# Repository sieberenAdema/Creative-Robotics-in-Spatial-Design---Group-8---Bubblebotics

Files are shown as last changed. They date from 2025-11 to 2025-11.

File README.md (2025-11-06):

### Creative Robotics in Spatial Design   Group 8 - Bubblebotics ###
ARIT1507 Creative Robotics in Spatial Design (2025/26 Q1) - Group 8 “Bubblebotics”
Soft pneumatic installation controlled by an ESP32 and a local voice interface.

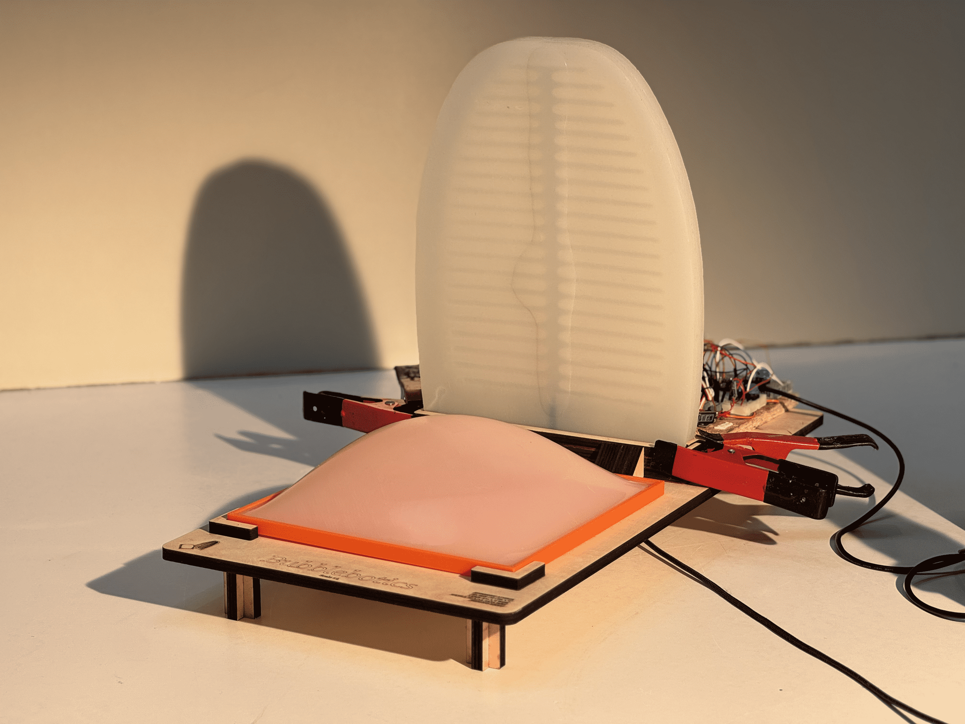
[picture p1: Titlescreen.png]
Bubblebotics


**TL;DR**: Speak a mood (Sleep / Play / Focus) → PC classifies the phrase → sends `MODE:*` over serial → ESP32 drives pump + valves to inflate/deflate a silicone petal and bubble → a synchronized video plays on a screen.

## 1) Project overview
This project explores ambient, soft robotic behaviors for spatial design.
Two soft pneumatic actuators (referred to as 'petal' and 'bubble') are controlled using an ESP32 microcontroller and a trained sentence classifier (all-MiniLM-L6-v2) running on a PC to parse voice inputs.

The three modes are:
- **Sleep** — calm, slow inflation (petal only)
- **Play** — lively, bigger motion (petal 2 + bubble)
- **Focus** — poised, attentive motion (petal 1 + bubble)

The actuators are made of flexible silicone that allow it to bend when air is pumped into it via a small tube.

Microphone → SpeechToText → Text Classifier → Serial Communication → ESP32 → Pump/Valves → Actuators
(from Text Classifier) → VLC → Screen Animation

---
## 2) Hardware
**Core components**
- An **ESP32 board (MicroPython)** to control the pump and solenoid valves.
- A **Grove 1.1 MOSFET driver board** to switch the pump on/off.
- Two silicone components, a **silicone pneumatic petal** and a **bubble actuator**, which inflates and bends when air is pumped in.
- A **12v Pump** to inflate the actuators
- A set of **4 12v solenoid valves** to control airflow to and from the actuators
- 3 **Buttons** to mannually actuate the different modes (The buttons are wired to ground. They use the internal Pull-ups on the ESP32)
- A **Breadboard** to connect all components, **tubing**, **printed manifolds**, **wireing** 

### ESP32 pinout
Refer to **wireing.svg** for exact wireing of all components

Making process video:
https://www.youtube.com/embed/A4v-PSnlZ5w?si=yJa3w9C8E-f-ZMew

## 3) Software
- **ESP32 (MicroPython v1.26.1)** runs valve/pump control and button handling.
- **Windows PC (Python)** runs voice → text, classifies to a mode, sends serial command, and drives VLC for videos.  

### Libraries used:
- **speechrecognition** — captures microphone audio and uses Google Web Speech API to transcribe short phrases.
- **sentence-transformers** — embeds text into vectors for semantic classification.
- **scikit-learn** — provides the probabilistic classifier used to map phrases → modes.
- **joblib** — loads the pre‑trained classifier from `model_classifier_augmented.pkl`.
- **numpy** — vector math for embeddings and probabilities.
- **pyserial** — lists serial ports and sends ASCII `MODE:*` lines to the ESP32 at 115200 baud.
- **python-vlc** — plays the inflate/deflate videos and loops the active mode video.
- **tkinter** — simple window to host the embedded VLC player.
- **collections.deque** — lightweight rolling log of recent phrases/modes.
- **MicroPython `machine`, `Pin`, `UART`** — access GPIO and optional UART on the ESP32.
- **MicroPython `select`** — non‑blocking read of USB CDC for serial commands.

## 4) Modes & behaviors
Timing constants (These are still being tuned and depend highly on the strength of pump used and the geometry of the silicone to be inflated):  
`INFLATE_TIME = 12 s` 
`DEFLATE_TIME = 6 s`

**Valve mapping per mode**
- **Sleep** : `Petal 1 = ON`, `Petal 2 = OFF`, `Bubble = OFF`, `Exhaust = OFF`
- **Play** : `Petal 1 = OFF`, `Petal 2 = ON`, `Bubble = ON`,  `Exhaust = OFF`
- **Focus** : `Petal 1 = ON`, `Petal 2 = OFF`, `Bubble = ON`,  `Exhaust = OFF`

**Cycle logic**
1) On mode change: **deflate** (open *all* valves + exhaust for 6 s)  
2) Then **inflate** the new mode: open that modes valves, run pump for 12 s, stop pump.

## 5) Steps required to get up and running
### A) Flash ESP32 with MicroPython (once)

- Use Windows Device Manager to detect which port the ESP32 is connected to
- Get the latest driver for ESP32 from https://micropython.org/download/ESP32_GENERIC/

```CMD
# Install tooling
python -m pip install --upgrade esptool mpremote setuptools
# Erase and flash (adjust COM port and .bin path)
esptool --port COM5 erase_flash
esptool --chip esp32 --port COM5 --baud 460800 \
  write_flash -z 0x1000 "C:\\Users\\flori\\Desktop\\indiv\\ESP32_GENERIC-20250911-v1.26.1.bin"
```
### B) Upload firmware to the board
```CMD
# List files on the board
mpremote connect COM5 fs ls

# Replace existing main.py
mpremote connect COM5 fs rm "main.py"   
mpremote connect COM5 fs cp "C:\\Users\\flori\\Desktop\\indiv\\main.py" :

# Run & view REPL output
mpremote connect COM5 run "C:\\Users\\flori\\Desktop\\indiv\\main.py"
mpremote connect COM5 repl
```
### C) Set up the PC app
```CMD
pip install speechrecognition sentence-transformers scikit-learn joblib pyserial python-vlc tkinter numpy
```
Place the files next to `main_with_video.py`:
```
model_classifier_augmented.pkl
embedder_augmented/            # SentenceTransformer folder or model reference
videos/
  sleep_inflation.mp4
  sleep_deflation.mp4
  play_inflation.mp4
  play_deflation.mp4
  focus_inflation.mp4
  focus_deflation.mp4
```
Ensure **VLC** is installed at `C:\Program Files\VideoLAN\VLC` (or x86). The script auto-adds that path.

### D) Run
```CMD
python path\to\main_with_video.py
```
- The script will auto‑detect the serial port (or set `SERIAL_PORT = "COM3"`).
- Speak phrases like “**I’m tired**” (Sleep), “**let’s play music**” (Play), “**I need to focus**” (Focus).
- The window should loop the current mode’s *inflate* video, and transition with *deflate* → *inflate* on changes.

## 6) Troubleshooting
- **No serial ports found** — Unplug the board. Check Device Manager. Try a different cable (make sure that the micro-USB is actually a data cable); set `SERIAL_PORT` explicitly in the code.
- **`libvlc.dll` not found** — Install VLC (desktop), then re‑run. Paths are auto‑added from `Program Files`.
- **Videos don’t play** — Verify file names and paths in `VIDEO_PATHS`.
- **Classifier always “low confidence”** — Lower `CONF_THRESHOLD` (e.g., 0.3) or add more training data. Speak closer to mic. Reduce background noise.
- **Pump acts weird / Valves act weird** — Check that wiring is correct, check that all wires are still in the right position.

## 7) Tips
- Make sure that the tubing is tight at valves, pump, manifold and silicone.
- Be carefull with the amount of pressure you add into the silicone actuators. In the current set-up the pump is strong enough rip the silicone should it run for too long.

## 8) References & handy commands

* MicroPython for ESP32: [https://micropython.org/download/ESP32_GENERIC/](https://micropython.org/download/ESP32_GENERIC/)
* `machine` module docs: [https://docs.micropython.org/en/latest/library/machine.html](https://docs.micropython.org/en/latest/library/machine.html)
* Getting started (ESP32/ESP8266): [https://randomnerdtutorials.com/getting-started-micropython-esp32-esp8266/](https://randomnerdtutorials.com/getting-started-micropython-esp32-esp8266/)
* ESP32 MicroPython tutorials: [https://newbiely.com/tutorials/esp32-micropython/esp32-micropython-ultrasonic-sensor](https://newbiely.com/tutorials/esp32-micropython/esp32-micropython-ultrasonic-sensor)
* Sentence transformer model: [https://huggingface.co/sentence-transformers/all-MiniLM-L6-v2](https://huggingface.co/sentence-transformers/all-MiniLM-L6-v2)

**Usefull CMD snippets**

```CMD
# File operations
mpremote connect COM5 fs ls
mpremote connect COM5 fs rm "main.py"
mpremote connect COM5 fs cp "C:\\Users\\flori\\Desktop\\indiv\\main.py" :
mpremote connect COM5 run "C:\\Users\\flori\\Desktop\\indiv\\main.py"
mpremote connect COM5 repl

# Run PC app
python "C:\\Users\\flori\\Desktop\\bubble\\brain_serial_llm.py"
python "C:\\Users\\flori\\Desktop\\bubble\\tinyllama_brain_serial_llm.py"
```

---

## 9) Cite

> Bubblebotics (2025). Creative Robotics in Spatial Design, TU Delft. https://github.com/sieberenAdema/Creative-Robotics-in-Spatial-Design---Group-8---Bubblebotics

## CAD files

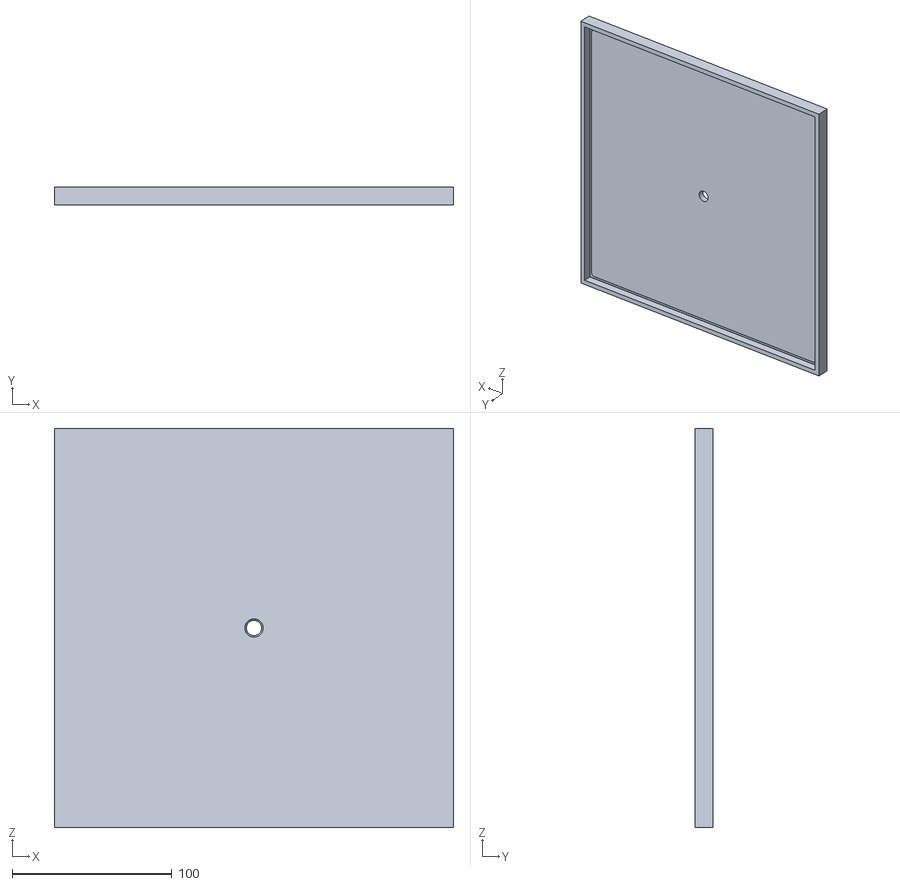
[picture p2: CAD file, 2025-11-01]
Geometry/250 bubble simple square.STL
250.0 x 11.0 x 250.0

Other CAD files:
Geometry/robot.dxf

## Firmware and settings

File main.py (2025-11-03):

# esp32_mode_control_serial.py
# Your valve/pump control + buttons + non-blocking serial listener for MODE:SLEEP/PLAY/FOCUS

from machine import Pin, UART
import sys, time

# CONFIGURE PINS (adjust as needed)
# Outputs
PUMP_PIN = 23          # MOSFET SIG (pump)
EXHAUST_VALVE_PIN = 18 # ULN input for exhaust valve (deflate)
PETAL_1_VALVE = 19     # ULN input for Sleep valve
PETAL_2_VALVE = 17     # ULN input for Play valve
BUBBLE_VALVE = 16      # ULN input for Bubble valve

# Inputs (buttons, active LOW)
BTN_SLEEP_PIN = 12
BTN_PLAY_PIN  = 13
BTN_FOCUS_PIN = 14

# Timing (seconds)
INFLATE_TIME = 10
DEFLATE_TIME = 7
DEBOUNCE_MS = 200

# SERIAL MODE
USE_USB_SERIAL = True  # True = read commands from USB CDC (no extra wires)
# If you want UART pins instead, set to False and configure below:
UART_PORT = 2           # UART(2) is usually free
UART_BAUD = 115200
UART_TX = 4             # pick free pins that don't clash!
UART_RX = 2

# SETUP HARDWARE
pump = Pin(PUMP_PIN, Pin.OUT)
exhaust_valve = Pin(EXHAUST_VALVE_PIN, Pin.OUT)
P_1_valve = Pin(PETAL_1_VALVE, Pin.OUT)
P_2_valve = Pin(PETAL_2_VALVE, Pin.OUT)
bubble_valve = Pin(BUBBLE_VALVE, Pin.OUT)

btn_sleep = Pin(BTN_SLEEP_PIN, Pin.IN, Pin.PULL_UP)
btn_play  = Pin(BTN_PLAY_PIN, Pin.IN, Pin.PULL_UP)
btn_focus = Pin(BTN_FOCUS_PIN, Pin.IN, Pin.PULL_UP)

if not USE_USB_SERIAL:
    uart = UART(UART_PORT, baudrate=UART_BAUD, tx=UART_TX, rx=UART_RX)

# Ensure everything off initially
def all_off():
    pump.value(0)
    exhaust_valve.value(0)
    P_1_valve.value(0)
    P_2_valve.value(0)
    bubble_valve.value(0)

all_off()

# Mode name constants
MODE_SLEEP = "Sleep"
MODE_PLAY  = "Play"
MODE_FOCUS = "Focus"
current_mode = MODE_PLAY

# HELPER FUNCTIONS
def set_mode_valves(mode):
    if mode == MODE_SLEEP:
        P_1_valve.value(1); P_2_valve.value(0); bubble_valve.value(0); exhaust_valve.value(0)
    elif mode == MODE_PLAY:
        P_1_valve.value(0); P_2_valve.value(0); bubble_valve.value(1); exhaust_valve.value(0)
    elif mode == MODE_FOCUS:
        P_1_valve.value(1); P_2_valve.value(0); bubble_valve.value(1); exhaust_valve.value(0)
    else:
        P_1_valve.value(0); P_2_valve.value(0); bubble_valve.value(0); exhaust_valve.value(0)

def deflate_cycle():
    print("Deflate: opening exhaust")
    pump.value(0)
    # open all valves so everything can dump
    exhaust_valve.value(1)
    P_1_valve.value(1)
    P_2_valve.value(1)
    bubble_valve.value(1)
    time.sleep(DEFLATE_TIME)
    # close exhaust
    exhaust_valve.value(0)
    P_1_valve.value(0)
    P_2_valve.value(0)
    bubble_valve.value(0)
    print("Deflate complete")

def inflate_for_mode(mode):
    print("Inflating for mode:", mode)
    set_mode_valves(mode)
    time.sleep(0.2)  # let valves open
    pump.value(1)
    time.sleep(INFLATE_TIME)
    pump.value(0)
    exhaust_valve.value(0)  # keep mode valves open
    print("Inflation done (pump stopped)")

def change_mode(new_mode):
    global current_mode
    if new_mode == current_mode:
        print("Already in", new_mode, "- no change")
        return
    print("Switching from", current_mode, "to", new_mode)
    deflate_cycle()
    inflate_for_mode(new_mode)
    current_mode = new_mode
    print("Mode is now", current_mode)

print("Starting - inflating initial mode:", current_mode)
inflate_for_mode(current_mode)

# BUTTONS (debounced)
last_btn_times = {"sleep": 0, "play": 0, "focus": 0}
def button_pressed(key):
    now = time.ticks_ms()
    last = last_btn_times[key]
    if time.ticks_diff(now, last) < DEBOUNCE_MS:
        return False
    last_btn_times[key] = now
    return True

# SERIAL PARSER (non-blocking)
# Accepts lines like: MODE:SLEEP / MODE:PLAY / MODE:FOCUS
buf = ""

def poll_serial_line():
    global buf
    try:
        if USE_USB_SERIAL:
            # read one char if available from USB CDC without blocking
            import select
            r, _, _ = select.select([sys.stdin], [], [], 0)
            if r:
                ch = sys.stdin.read(1)
            else:
                ch = None
        else:
            if not hasattr(uart, "any") or not uart.any():
                ch = None
            else:
                ch = uart.read(1)
                if ch is not None:
                    ch = ch.decode("utf-8", "ignore")
        if ch:
            buf += ch
            if ch == "\n":
                line = buf.strip()
                buf = ""
                return line
    except Exception as e:
        # swallow transient decode/IO issues
        buf = ""
    return None

def handle_command(line: str):
    up = line.strip().upper()
    if up == "MODE:SLEEP":
        change_mode(MODE_SLEEP)
    elif up == "MODE:PLAY":
        change_mode(MODE_PLAY)
    elif up == "MODE:FOCUS":
        change_mode(MODE_FOCUS)
    else:
        print("Unknown command:", line)

# MAIN LOOP

try:
    while True:
        # 1) Serial
        line = poll_serial_line()
        if line:
            print("Received:", line)
            handle_command(line)

        # 2) Buttons (active LOW)
        if btn_sleep.value() == 0 and button_pressed("sleep"):
            change_mode(MODE_SLEEP)
        elif btn_play.value() == 0 and button_pressed("play"):
            change_mode(MODE_PLAY)
        elif btn_focus.value() == 0 and button_pressed("focus"):
            change_mode(MODE_FOCUS)

        time.sleep_ms(30)

except KeyboardInterrupt:
    print("Interrupted, turning everything off")
    all_off()

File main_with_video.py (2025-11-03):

# voice_to_mode_videos_fixed.py
# Mic → Google STT → Local Classifier → MODE:SLEEP/PLAY/FOCUS over serial
# + VLC video transitions (deflate old mode → inflate new mode)
#
# Requires:
# pip install speechrecognition sentence-transformers scikit-learn joblib pyserial python-vlc tkinter

import os
import time
import threading
import serial, serial.tools.list_ports
import speech_recognition as sr
from sentence_transformers import SentenceTransformer
import joblib
import numpy as np
from collections import deque
import tkinter as tk
import vlc

# ========== VLC SETUP ==========
VLC_PATHS = [
    r"C:\Program Files\VideoLAN\VLC",
    r"C:\Program Files (x86)\VideoLAN\VLC",
]
for p in VLC_PATHS:
    if os.path.exists(os.path.join(p, "libvlc.dll")):
        os.add_dll_directory(p)
        print(f"[VLC] Using VLC from: {p}")
        break

# ========== SERIAL CONFIGURATION ==========
SERIAL_PORT = "COM3"  # Set to None to autodetect
BAUD = 115200
SERIAL_COOLDOWN_S = 3
CONF_THRESHOLD = 0.4   # less strict threshold for smoother recognition
PRINT_TRANSCRIPTS = True
CONTEXT_WINDOW = 5

conversation_log = deque(maxlen=CONTEXT_WINDOW)

# ========== CLASSIFIER LOADING ==========
embedder = SentenceTransformer("embedder_augmented")
clf = joblib.load("model_classifier_augmented.pkl")
LABEL_MAP = {0: "MODE:SLEEP", 1: "MODE:PLAY", 2: "MODE:FOCUS"}

# ========== VIDEO PATHS ==========
# You have 6 videos: 3 inflate + 3 deflate
VIDEO_PATHS = {
    "MODE:SLEEP": {"inflate": "videos/sleep_inflation.mp4", "deflate": "videos/sleep_deflation.mp4"},
    "MODE:PLAY":  {"inflate": "videos/play_inflation.mp4",  "deflate": "videos/play_deflation.mp4"},
    "MODE:FOCUS": {"inflate": "videos/focus_inflation.mp4", "deflate": "videos/focus_deflation.mp4"},
}

# ========== SPEECH RECOGNITION ==========
rec = sr.Recognizer()
mic = sr.Microphone()

def transcribe_once() -> str | None:
    with mic as source:
        rec.adjust_for_ambient_noise(source, duration=0.4)
        print("🎤 Listening...")
        audio = rec.listen(source, phrase_time_limit=8)
    try:
        text = rec.recognize_google(audio)
        if PRINT_TRANSCRIPTS:
            print(f"You said: {text}")
        return text
    except sr.UnknownValueError:
        print("(couldn't understand)")
        return None
    except sr.RequestError as e:
        print(f"(speech service error: {e})")
        return None

# ========== SERIAL HELPERS ==========
def autodetect_port():
    ports = list(serial.tools.list_ports.comports())
    if not ports:
        raise RuntimeError("No serial ports found.")
    for p in ports:
        if any(tag in (p.description or "") for tag in ["USB", "CP210", "CH340", "Silicon", "UART"]):
            return p.device
    return ports[0].device

def open_serial():
    port = SERIAL_PORT or autodetect_port()
    ser = serial.Serial(port, BAUD, timeout=0.2)
    print(f"[serial] connected on {ser.port}")
    time.sleep(1.0)
    return ser

# ========== CLASSIFIER HELPERS ==========
def classify_mode_local(text: str):
    vec = embedder.encode([text])
    probs = clf.predict_proba(vec)[0]
    pred = int(np.argmax(probs))
    conf = float(np.max(probs))
    if conf < CONF_THRESHOLD:
        print(f"(low confidence: {conf:.2f} — ignoring)")
        return None
    print(f"[classifier] predicted {LABEL_MAP[pred]} ({conf:.2f})")
    return pred

def mode_to_command(m: int) -> str:
    return LABEL_MAP[m]

# ========== TKINTER + VLC WINDOW ==========
root = tk.Tk()
root.title("Ambient Space Display")
root.geometry("1280x720")
root.configure(bg="black")

embed_frame = tk.Frame(root, bg="black")
embed_frame.pack(fill="both", expand=True)

instance = vlc.Instance("--no-xlib")
player = instance.media_player_new()
root.update_idletasks()
player.set_hwnd(embed_frame.winfo_id())

# ========== VIDEO CONTROL ==========
player_busy = threading.Event()
current_mode = "MODE:SLEEP"  # start mode

def play_video(path: str, block=False, loop=False, timeout=30):
    """Play a video. Optionally block until finished (with timeout) or loop manually."""
    global player_busy
    if not os.path.exists(path):
        print(f"[video] Missing file: {path}")
        return

    # Stop current playback
    if player.is_playing():
        player.stop()
        time.sleep(0.3)

    media = instance.media_new(path)
    player.set_media(media)
    player.play()
    player_busy.set()
    print(f"[video] playing {os.path.basename(path)}")

    # Attach event BEFORE playback ends
    def on_end(event):
        print(f"[video] finished: {os.path.basename(path)}")
        if loop:
            print(f"[video] looping {os.path.basename(path)}")
            player.play()
        else:
            player_busy.clear()

    em = player.event_manager()
    em.event_detach(vlc.EventType.MediaPlayerEndReached)
    em.event_attach(vlc.EventType.MediaPlayerEndReached, on_end)

    # Blocking mode with timeout
    if block:
        start = time.time()
        while player_busy.is_set():
            time.sleep(0.1)
            if time.time() - start > timeout:
                print(f"[video] timeout waiting for {os.path.basename(path)} to finish")
                player_busy.clear()
                break


def transition_to_mode(new_mode: str):
    """Play deflate of old mode, then inflate of new mode."""
    global current_mode
    if new_mode == current_mode:
        print(f"[video] already in {new_mode}, skipping transition")
        return

    print(f"[video] Transition: {current_mode} → {new_mode}")

    # 1️⃣ Deflate previous mode
    deflate_path = VIDEO_PATHS.get(current_mode, {}).get("deflate")
    if deflate_path:
        play_video(deflate_path, block=True, timeout=25)
    else:
        print(f"[video] no deflate video for {current_mode}")

    # 2️⃣ Inflate new mode (looped)
    inflate_path = VIDEO_PATHS.get(new_mode, {}).get("inflate")
    if inflate_path:
        play_video(inflate_path, loop=True)
    else:
        print(f"[video] no inflate video for {new_mode}")

    current_mode = new_mode


# ========== INITIAL VIDEO ==========
play_video(VIDEO_PATHS["MODE:SLEEP"]["inflate"], loop=True)
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

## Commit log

2025-10-29 Update actuator terminology in README.md
2025-10-30 Enhance README with detailed hardware and software info
    Expanded hardware and software sections in README.md, added ESP32 pinout, modes and behaviors, steps to get started, troubleshooting tips, and coding application details.
2025-11-01 Wiring diagram showing the current setup with pump, valves, ESP32 and buttons
2025-11-01 Change wiring reference from circuit.png to wiring.svg
    Updated the reference image for wiring in the README.
2025-11-01 Lasercut template to cut the mold of the petal
    [robot.dxf]
2025-11-01 STL for the bubble mold
    Needs a FMD print bed size of at least 250x250.
    Layer height: 0.36mm
    Nozzle: 0.6 mm
    Material: PLA
    No supports
    Tape the air hole in the middle when pouring silicone
    [250 bubble simple square.STL]
2025-11-01 Update README with heading for system flow
2025-11-01 Correct flow diagram formatting in README
    Fix formatting and improve readability of the flow diagram.
2025-11-06 Rename 250 bubble simple square.STL to Geometry/250 bubble simple square.STL
    [250 bubble simple square.STL]
